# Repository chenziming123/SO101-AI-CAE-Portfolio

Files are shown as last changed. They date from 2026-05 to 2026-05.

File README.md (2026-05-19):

# SO-101 AI-Assisted CAD/CAE Robotic Arm Structure Project

> 基于开源 SO-101 follower arm 的 AI 辅助机械结构建模、参数化 CAD 迭代、URDF/PyBullet 回归验证和 CalculiX/Gmsh 有限元分析项目。

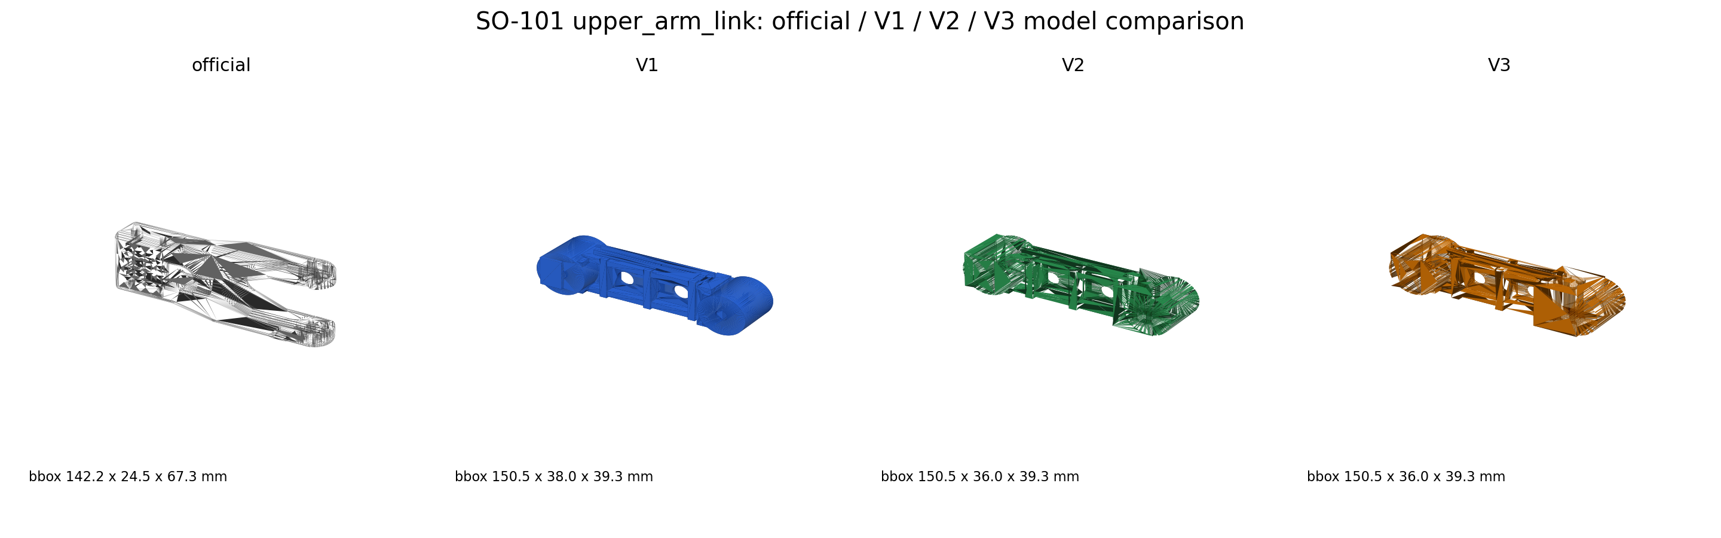
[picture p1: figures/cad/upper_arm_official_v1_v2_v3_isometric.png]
CAD iteration


## 项目定位

这个项目的目标不是只生成一个“看起来像机械臂”的模型，而是建立一条可以面向机械结构岗位展示的工程链：

1. 复现 SO-101 机械臂 baseline，并读取 CAD/STL/URDF 结构资源。
2. 对 official upper arm 做工作空间、静载力矩和结构瓶颈分析。
3. 使用 AI + CAD-as-code 思路生成 V1/V2/V3 参数化 upper arm。
4. 导出 STEP/STL，做孔位、沉孔、标准件装配和 URDF smoke test。
5. 使用 Gmsh / CalculiX / PyVista 对 official 与 V3 做同边界条件有限元对比。
6. 把模型、图片、数据、脚本和中文报告整理成可复核的作品集。

## 核心结果

| 版本 | 定位 | PLA 质量估算 | 体积变化 | 装配校核 | PyBullet smoke test |
|---|---|---:|---:|---|---|
| official | 开源 baseline | 145.49 g | 0.00% | 官方基准 | 通过 |
| V1 | 轻量化概念版 | 116.42 g | -19.98% | 关键接口不完整 | 通过 |
| V2 | 装配接口增强版 | 122.30 g | -15.94% | PASS | 通过 |
| V3 | 孔系余量修正版 | 126.35 g | -13.16% | PASS | 通过 |

full V3 clean FEA screening 结果：

| 版本 | 网格尺寸 | 节点数 | 四面体数 | 质量 | 最大位移 | 最大 von Mises | 屈服安全系数 |
|---|---:|---:|---:|---:|---:|---:|---:|
| official | 5.0 mm | 3750 | 12410 | 144.07 g | 0.024591 mm | 0.327 MPa | 153.11 |
| full V3 | 5.0 mm | 3255 | 11048 | 127.49 g | 0.071577 mm | 0.770 MPa | 64.96 |

结论：V3 相对 official 质量降低约 `11.51%`，但最大位移和应力上升，说明后续 V4 应优先加强中部梁、上下梁连接和肋板布局，而不是继续盲目减重。

## 仓库结构

```text
docs/      中文项目报告、流程说明、FEA 结论、工程说明
figures/   建模、仿真、FEA 和数据图
models/    V1/V2/V3 STEP/STL、装配检查模型、FEA clean STEP
data/      CSV/JSON 指标、孔位检查、力矩对比、FEA 结果
src/       CAD 生成、结构分析、URDF smoke test、FEA 脚本
tools/     项目辅助脚本
projects/  可独立查看的工程模块资料包
```

## 推荐阅读顺序

1. [`docs/01_project_overview_zh.md`](docs/01_project_overview_zh.md)
2. [`docs/02_cad_iteration_v1_v2_v3_zh.md`](docs/02_cad_iteration_v1_v2_v3_zh.md)
3. [`docs/03_fea_full_v3_clean_zh.md`](docs/03_fea_full_v3_clean_zh.md)
4. [`docs/04_text_to_cad_open_source_workflow_zh.md`](docs/04_text_to_cad_open_source_workflow_zh.md)
5. [`projects/text_to_cad_parametric_cad/README_zh.md`](projects/text_to_cad_parametric_cad/README_zh.md)
6. [`docs/08_text_to_cad_parametric_cad_workflow_zh.md`](docs/08_text_to_cad_parametric_cad_workflow_zh.md)
7. [`docs/05_project_explanation_zh.md`](docs/05_project_explanation_zh.md)

## 工程模块与证据目录

| 工程模块 | GitHub 对应内容 |
|---|---|
| Text-to-CAD机械结构参数化建模与工程校核流程 | [`projects/text_to_cad_parametric_cad/README_zh.md`](projects/text_to_cad_parametric_cad/README_zh.md)、[`docs/08_text_to_cad_parametric_cad_workflow_zh.md`](docs/08_text_to_cad_parametric_cad_workflow_zh.md) |
| SO-101机械臂结构仿真、装配验证与有限元分析 | [`docs/02_cad_iteration_v1_v2_v3_zh.md`](docs/02_cad_iteration_v1_v2_v3_zh.md)、[`docs/03_fea_full_v3_clean_zh.md`](docs/03_fea_full_v3_clean_zh.md)、`figures/fea/`、`data/fea/` |

## 关键图片

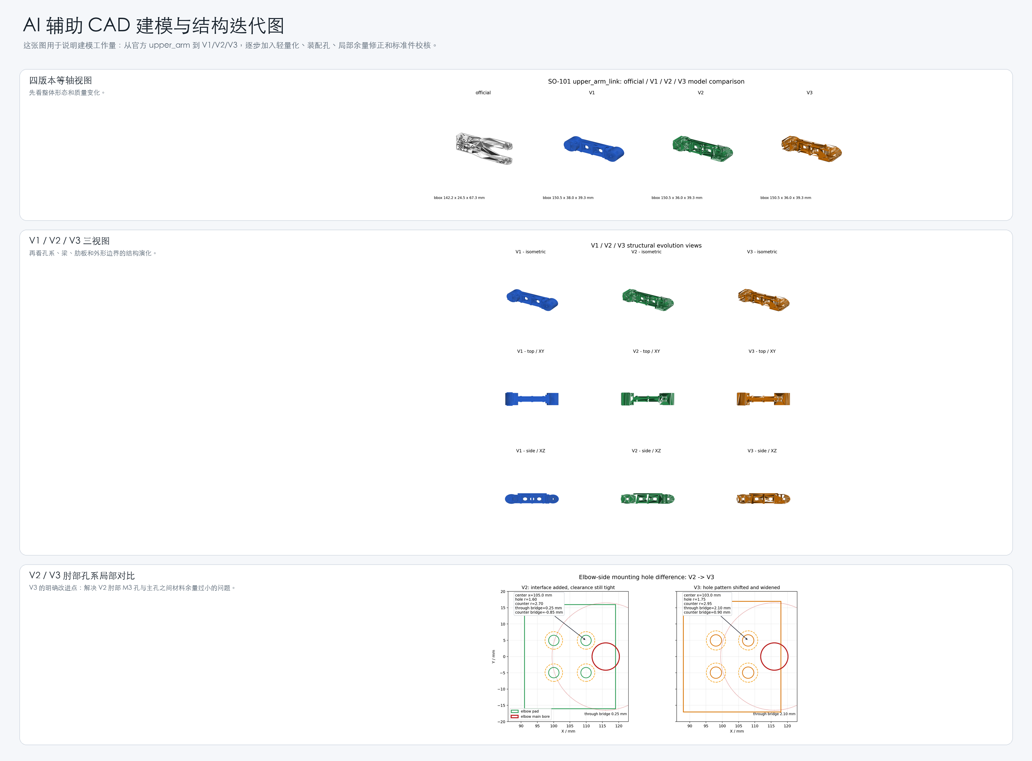
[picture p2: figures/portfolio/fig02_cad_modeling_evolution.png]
CAD evolution


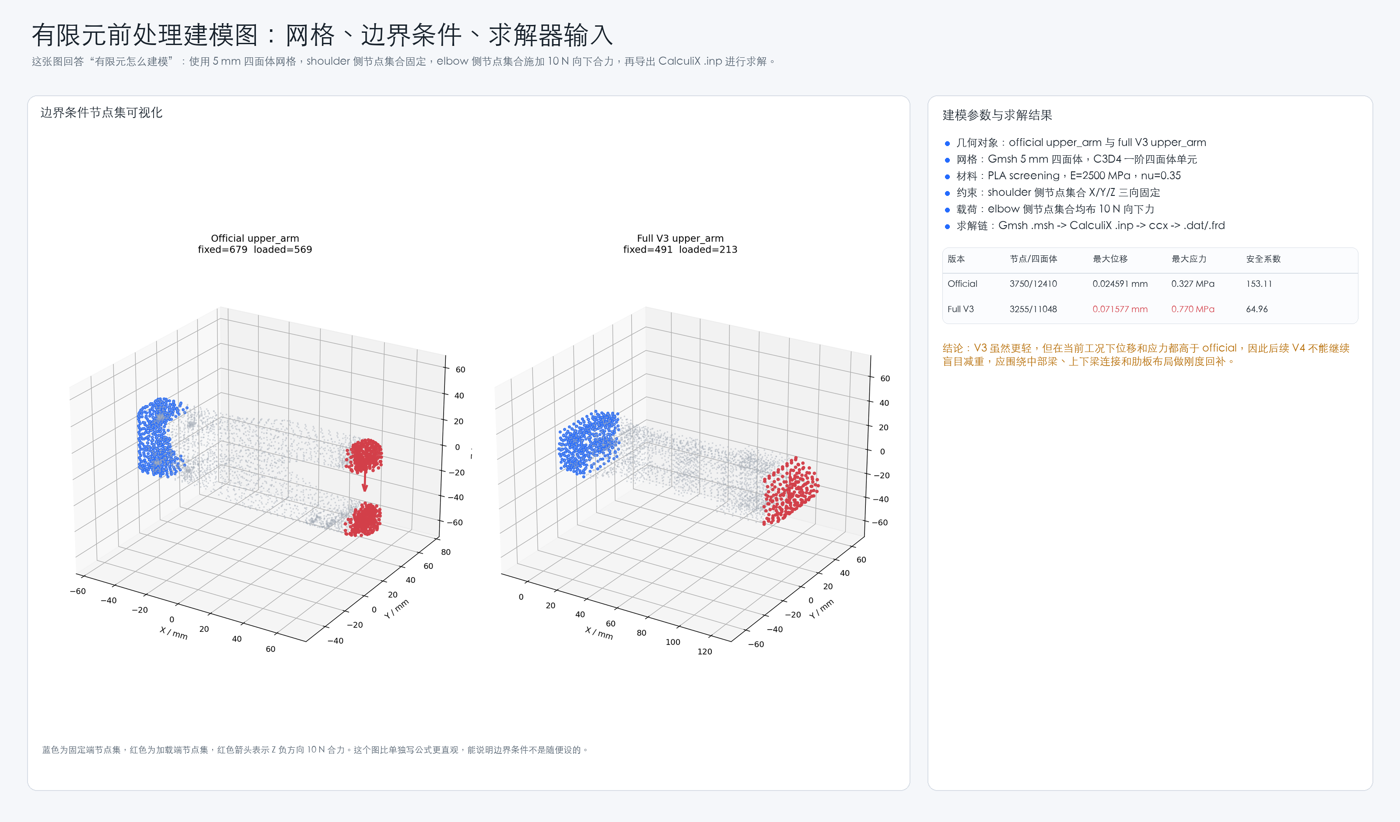
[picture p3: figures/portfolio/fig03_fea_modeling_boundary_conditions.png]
FEA boundary


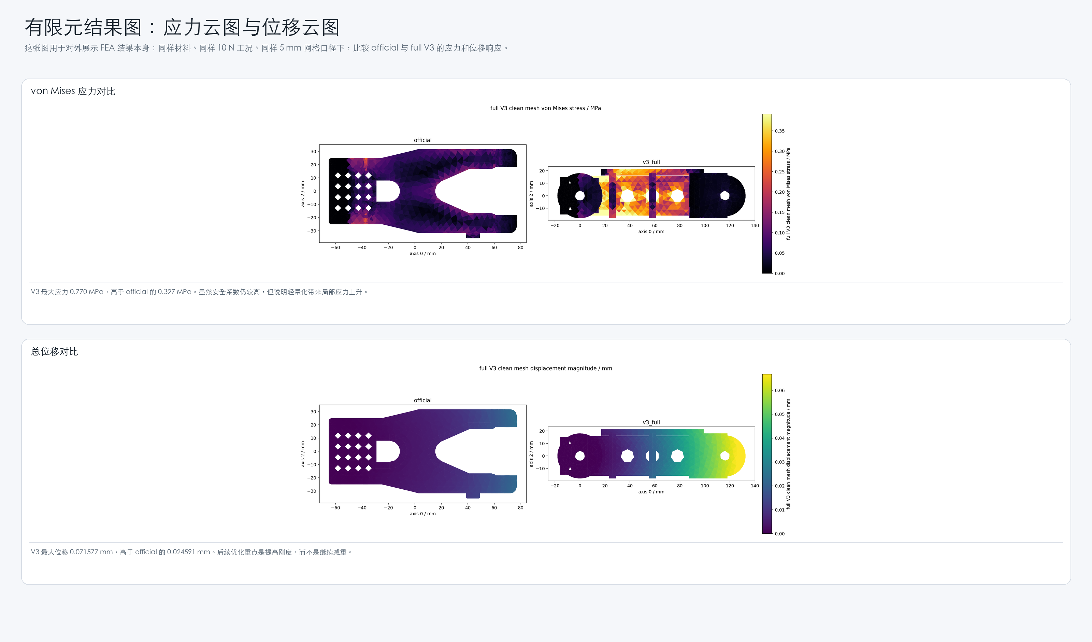
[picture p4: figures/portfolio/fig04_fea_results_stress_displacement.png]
FEA results


## 复现实验环境

主要 Python 依赖：

- CAD 建模：`build123d`, `OCP`, `trimesh`
- 仿真/数据：`numpy`, `scipy`, `matplotlib`, `pybullet`
- 网格与 FEA 后处理：`gmsh`, `meshio`, `pyvista`
- 求解器：`CalculiX ccx`

完整环境建议见 [`docs/06_toolchain_feasibility_zh.md`](docs/06_toolchain_feasibility_zh.md)。

## 说明

本仓库是作品集整理版，只包含公开展示所需的模型、图片、数据、报告和代码。个人资料、联系方式、服务器凭据、临时缓存和完整私有工作目录没有上传。

SO-101 baseline 资源来自开源项目，相关第三方资源权利归原项目所有；本仓库中的 AI 辅助 CAD/CAE 脚本、分析报告和整理图表用于学习与作品集展示。

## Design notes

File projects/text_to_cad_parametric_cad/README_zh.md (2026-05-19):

# Text-to-CAD 参数化机械结构建模与工程校核

本目录把 Text-to-CAD 相关的模型、图片、数据和代码集中在一起，便于独立查看这一模块的工程链路。

## 模块目标

将自然语言结构需求转化为可复现的参数化 CAD 脚本，并通过 STEP/STL 导出、B-Rep 特征校核、标准件装配检查、URDF 回归和 FEA 前处理验证模型可用性。

## 目录结构

```text
figures/      CAD 迭代图、三视图、孔系局部差异图
data/         体积/质量指标、孔位校核、装配检查 JSON/CSV
code/cad/     V1/V2/V3 CAD 生成、验证、孔位检查和 URDF smoke test 代码
models/       V1/V2/V3 STEP/STL 模型
assemblies/   V2/V3 简化标准件装配 STEP/STL
reports/      V1/V2/V3 设计报告和孔位校核报告
```

## 核心流程

```mermaid
flowchart LR
  A["结构需求"] --> B["参数拆解"]
  B --> C["build123d / OCP 建模脚本"]
  C --> D["STEP / STL 导出"]
  D --> E["B-Rep 圆柱特征识别"]
  E --> F["孔位 / 沉孔 / 装配余量检查"]
  F --> G["标准件简化装配"]
  G --> H["URDF / PyBullet 回归"]
  H --> I["FEA 前处理与下一版改进"]
```

## 模型迭代

| 版本 | 文件 | 设计目标 | 工程校核 |
|---|---|---|---|
| V1 | `models/upper_arm_v1_ai_rebuild.step` | 轻量化概念重建 | 可导出 STEP/STL，关键装配接口不足 |
| V2 | `models/upper_arm_v2_ai_rebuild.step` | 补齐 M3 孔、沉孔、肩部夹紧/定位孔 | 装配表达更完整，肘部孔系余量偏紧 |
| V3 | `models/upper_arm_v3_ai_rebuild.step` | 修正肘部孔位、孔径、沉孔和局部 pad | 孔位复核 PASS，标准件装配检查 PASS |

## 关键图

CAD evolution

Official V1 V2 V3

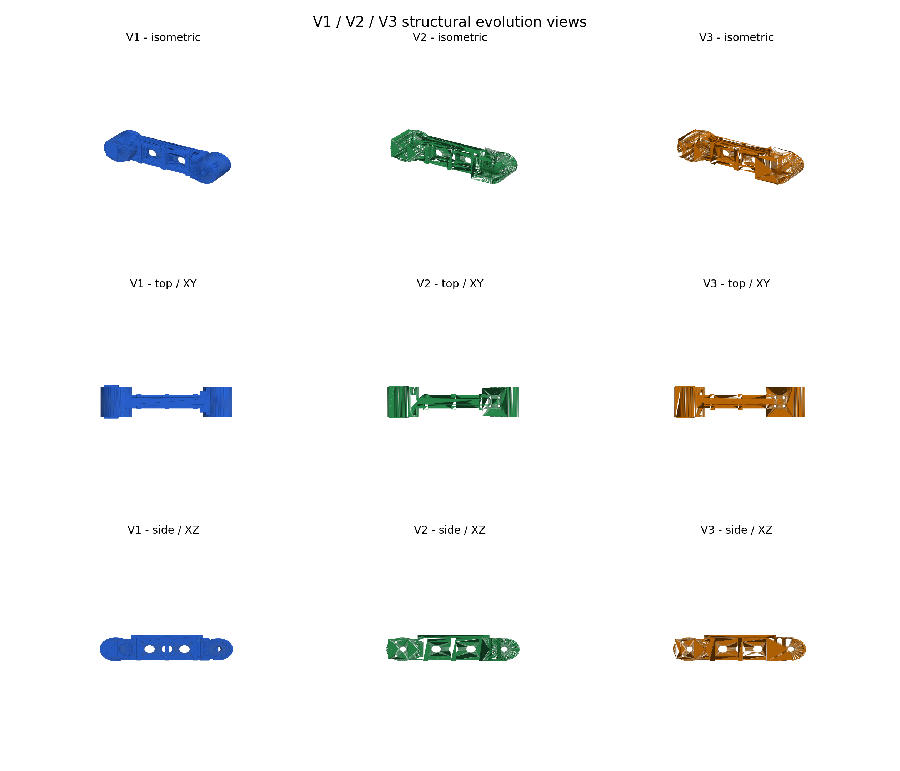
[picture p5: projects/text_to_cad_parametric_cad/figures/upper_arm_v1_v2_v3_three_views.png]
Three views


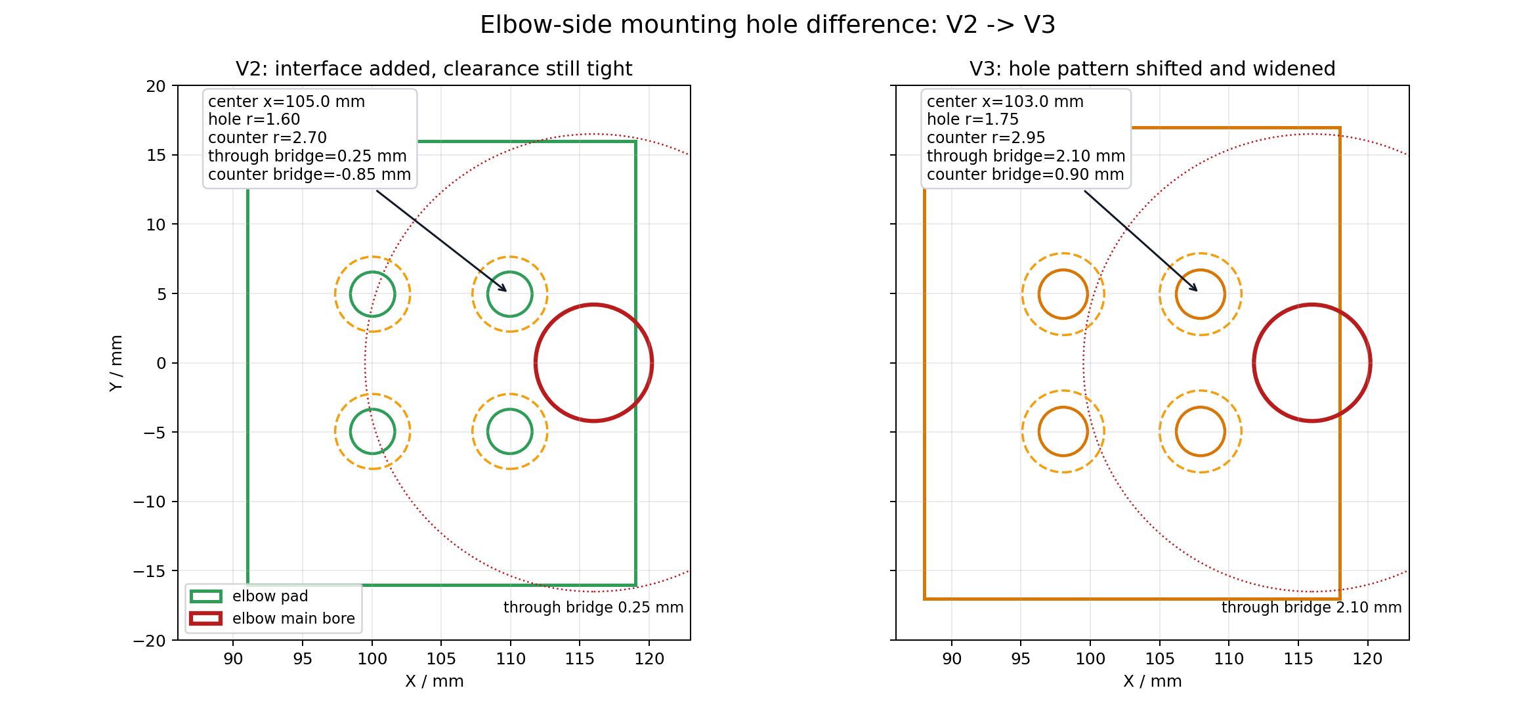
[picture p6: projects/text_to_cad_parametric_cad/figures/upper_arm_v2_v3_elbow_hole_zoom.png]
Elbow hole zoom


## 数据文件

关键汇总：

- `data/upper_arm_v1_v2_v3_key_metrics.csv`

V1/V2/V3 CAD 验证：

- `data/upper_arm_v1_validation.json`
- `data/upper_arm_v2_validation.json`
- `data/upper_arm_v3_validation.json`

孔位与圆柱特征校核：

- `data/upper_arm_v1_mounting_check.json`
- `data/upper_arm_v2_mounting_check.json`
- `data/upper_arm_v3_mounting_check.json`
- `data/upper_arm_v1_mounting_cylinders.csv`
- `data/upper_arm_v2_mounting_cylinders.csv`
- `data/upper_arm_v3_mounting_cylinders.csv`

标准件装配检查：

- `data/upper_arm_v2_standard_part_check.json`
- `data/upper_arm_v2_standard_part_checks.csv`
- `data/upper_arm_v3_standard_part_check.json`
- `data/upper_arm_v3_standard_part_checks.csv`

## 代码入口

CAD 生成：

```bash
python code/cad/upper_arm_v1/upper_arm_v1_cad.py
python code/cad/upper_arm_v2/upper_arm_v2_cad.py
python code/cad/upper_arm_v3/upper_arm_v3_cad.py
```

几何与孔位校核：

```bash
python code/cad/upper_arm_v1/validate_upper_arm_v1.py
python code/cad/upper_arm_v2/validate_upper_arm_v2.py
python code/cad/upper_arm_v3/validate_upper_arm_v3.py

python code/cad/upper_arm_v1/upper_arm_v1_mounting_check.py
python code/cad/upper_arm_v2/upper_arm_v2_mounting_check.py
python code/cad/upper_arm_v3/upper_arm_v3_mounting_check.py
```

标准件装配检查：

```bash
python code/cad/upper_arm_v2/upper_arm_v2_standard_part_assembly_check.py
python code/cad/upper_arm_v3/upper_arm_v3_standard_part_assembly_check.py
```

URDF / PyBullet 回归：

```bash
python code/cad/upper_arm_v1/upper_arm_v1_urdf_smoke.py
python code/cad/upper_arm_v2/upper_arm_v2_urdf_smoke.py
python code/cad/upper_arm_v3/upper_arm_v3_urdf_smoke.py
```

## 工程结论

Text-to-CAD 在本项目中的作用不是替代工程验证，而是提高结构方案生成和参数化建模效率。最终模型必须经过 STEP 特征级孔位校核、标准件装配检查、URDF/PyBullet 回归和 FEA 结果约束，才能进入下一轮结构设计。

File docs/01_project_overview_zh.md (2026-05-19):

# 项目总览：SO-101 AI 辅助机械臂结构建模与 CAE 验证

## 项目目标

围绕开源 SO-101 follower arm，构建一个面向机械结构/CAE 岗位的作品集项目。项目强调“AI 参与工程流程”，但不把 AI 输出当作最终答案，而是用 CAD 特征校核、URDF 运动学回归、静载力矩分析和有限元结果反向约束设计。

## 技术路线

```mermaid
flowchart LR
  A["开源 SO-101 baseline"] --> B["CAD/STL/URDF 资产盘点"]
  B --> C["PyBullet baseline 运动验证"]
  C --> D["工作空间和静载力矩分析"]
  D --> E["锁定 upper_arm_link 优化对象"]
  E --> F["AI + 参数化 CAD 生成 V1/V2/V3"]
  F --> G["STEP/STL 导出与孔位校核"]
  G --> H["URDF smoke test 与力矩回归"]
  H --> I["Gmsh/CalculiX 静力有限元"]
  I --> J["V4 结构加强方向"]
```

## 作品集中能体现的能力

- 机械结构拆解：从整机中定位 upper arm 的结构和受力角色。
- CAD 建模：用参数化脚本生成可导出的 STEP/STL，而不是只做图片。
- 装配意识：检查孔位、沉孔、标准件和接口余量。
- 仿真闭环：把 CAD 改动接回 URDF/PyBullet 验证运动链。
- CAE 能力：搭建 Gmsh/CalculiX 有限元流程，输出应力/位移/安全系数。
- AI 辅助工程：用 AI 提高建模、脚本、报告和设计迭代效率，同时用工程校核约束 AI 结果。

## 当前阶段结论

V3 已经实现了从 CAD 到 URDF 到 FEA 的完整闭环。它相对 official 更轻，但 full V3 FEA 结果显示刚度下降明显，下一阶段应基于 FEA 结果设计 V4，加强中部梁、上下梁连接和肋板布局。

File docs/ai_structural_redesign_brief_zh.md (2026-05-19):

# SO-101 Follower AI 结构重建设计 Brief

## 目标

使用 AI 辅助 CAD 生成方法，对 SO-101 的选定结构件进行参数化重建和局部改进，同时保留官方机械臂的运动学结构。

## 必须保留的内容

- 保留官方 joint 名称、joint axis 和运动链。
- 第一轮重建设计中保留 `shoulder_lift`、`elbow_flex`、`wrist_flex`、`wrist_roll` 和 gripper frame 的位置。
- 保留舵机安装接口、舵盘间隙、螺丝孔位和 URDF link 归属关系。
- 不修改 `00_source_snapshot/`；所有改进版 CAD 放在 `05_improved_design/`。

## 来自 URDF 的关键 Baseline 尺寸

- shoulder_lift 到 elbow_flex 近似跨度：116.0 mm
- elbow_flex 到 wrist_flex 近似跨度：135.0 mm
- wrist_flex 到 wrist_roll 近似跨度：63.7 mm
- wrist/gripper frame offset 贡献：98.4 mm

## 重建设计目标

### 目标 1：upper_arm_link

- 控制关节：`shoulder_lift`
- 风险分数：100.0 / 100
- baseline p95 弯矩：1.1496 Nm
- 简化 p95 转角估计：2.660 deg
- 改进方向：通过加强筋、盒式截面和线槽提高弱轴刚度，同时不移动肩部和肘部关节 frame。
- 必须保留的接口：保留 `shoulder_lift` 和 `elbow_flex` 的 joint origin、axis、舵盘间隙和螺丝安装接口。

### 目标 2：lower_arm_link

- 控制关节：`elbow_flex`
- 风险分数：73.4 / 100
- baseline p95 弯矩：0.7142 Nm
- 简化 p95 转角估计：2.158 deg
- 改进方向：降低远端质量，并在腕部电机座和线束应力释放区域增加局部加强。
- 必须保留的接口：保留 `elbow_flex` 和 `wrist_flex` 的 joint origin、腕部电机座对齐关系和腕部安装孔位。

### 目标 3：wrist_gripper_module

- 控制关节：`wrist_flex`
- 风险分数：53.2 / 100
- baseline p95 弯矩：0.2725 Nm
- 简化 p95 转角估计：2.194 deg
- 改进方向：降低远端质量，增加紧凑局部加强筋，并加入可换指尖或小型工具法兰。
- 必须保留的接口：保留 `wrist_flex`、`wrist_roll`、`gripper` joint frame、tool frame 和夹爪开合几何兼容性。

## 第一版改进 CAD 的成功标准

- 输出可编辑的 build123d/Python CAD 源文件，并导出 STEP/STL。
- 工作空间可达性接近官方 baseline。
- 在不改变运动学 frame 的前提下，降低远端质量或提高弱轴有效刚度。
- mesh 替换后通过 PyBullet URDF 加载和随机运动 smoke test。
- 如果质量、刚度或工作空间出现取舍，必须在报告中明确说明。

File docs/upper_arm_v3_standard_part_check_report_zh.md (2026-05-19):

# upper_arm_v3 标准件装配与简化干涉检查报告

## 这一步在做什么

Step 15 针对 Step 14 在 V2 中发现的肘部孔系余量问题，生成 V3 的简化标准件装配检查。

本步骤用简化 D8 主轴、M3 螺钉、M3 螺钉头和简化舵机连接板，检查 V3 的孔径、沉孔、孔间材料和 pad 边缘材料是否可接受。

## V3 相比 V2 的修改

- 肘部 2x2 安装孔中心从 x=105.0 mm 移到 x=103.0 mm，让孔系远离 elbow 主孔。
- 肘部 M3 通孔半径从 1.60 mm 放宽到 1.75 mm，提高打印后螺钉装入成功率。
- 肘部 M3 沉孔半径从 2.70 mm 放宽到 2.95 mm，提高螺钉头装配余量。
- 肘部 pad 从 28 x 32 x 35 mm 增加到 30 x 34 x 36 mm，用局部加厚抵消放宽孔径带来的材料削弱。

## 标准件简化假设

- 主关节轴/轴套：半径 4.00 mm，对应约 D8 标准件包络。
- 肘部安装螺钉：M3 简化螺钉，杆部半径 1.50 mm，头部半径 2.60 mm，高度 2.00 mm。
- 肩部夹紧/定位螺钉：M3 简化螺钉，杆部半径 1.50 mm，外侧头部半径 3.00 mm。
- 肘部简化舵机/连接板 footprint：22.0 x 22.0 mm。

## 总体结论

- 装配检查总体状态：`PASS`。
- FAIL 项数量：0。
- WARN 项数量：0。
- Step 14 中 V2 的 3 个装配余量 WARN 项在 V3 中已消除。

## 检查明细

| 检查项 | 要求 | 实测/计算 | 状态 | 说明 |
|---|---|---|---|---|
| 主关节 D8 轴/轴套径向余量 | 孔半径 4.20 mm，应大于标准件半径 4.00 mm | 0.200 mm | PASS | 用于判断 shoulder/elbow 主轴或轴套是否能装入。 |
| 肘部 M3 螺钉通孔径向余量 | 孔半径 1.75 mm，应大于 M3 螺钉半径 1.50 mm | 0.250 mm | PASS | V3 已将 V2 的偏紧通孔放宽，给 3D 打印误差留出更稳定余量。 |
| 肘部 M3 螺钉头沉孔径向余量 | 沉孔半径 2.95 mm，应大于头部半径 2.60 mm | 0.350 mm | PASS | V3 已放宽沉孔半径，降低实际螺钉头装不进去的风险。 |
| 肘部 M3 螺钉头沉孔深度余量 | 沉孔深度 2.40 mm，应大于头部高度 2.00 mm | 0.400 mm | PASS | 沉孔深度可容纳简化螺钉头。 |
| 肘部安装孔到 pad 边缘最小材料 | 建议 >= 2.0 mm | 通孔边缘 8.300 mm，沉孔边缘 7.100 mm | PASS | V3 同时加大 elbow pad，使放宽孔径后仍保留边缘材料。 |
| 肘部 2x2 孔间最小材料 | 建议通孔/沉孔之间保留 >= 2.0 mm | 通孔间 6.400 mm，沉孔间 4.000 mm | PASS | 孔系自身材料余量仍可接受。 |
| 肘部安装孔与 elbow 主孔最小孔间材料 | 保守按沉孔外缘建议 >= 0.8 mm | 通孔外缘 2.100 mm，沉孔外缘 0.900 mm | PASS | 这是 Step 14 的主要风险项。V3 将孔系向近端移动后，最近 M3 孔与 elbow 主孔之间的材料桥明显增加。 |
| 肩部 M3 夹紧/定位孔径向余量 | 孔半径 2.00 mm，应大于 M3 螺钉半径 1.50 mm | 0.500 mm | PASS | 肩部侧向孔给 M3 螺钉留有较宽松余量。 |
| 肩部夹紧孔到 pad 边缘最小材料 | 建议 >= 2.0 mm | 2.500 mm | PASS | V3 没有改肩部接口，该项继承 V2 的可接受结果。 |
| 肩部夹紧孔与 shoulder 主孔最小孔间材料 | 建议 >= 2.0 mm | 7.000 mm | PASS | 肩部夹紧孔与主孔之间有较充足材料。 |
| 简化舵机/连接板 footprint 是否落在 elbow pad 内 | 参考板投影应在 pad 内 | 最小边缘余量 4.000 mm | PASS | 用于检查简化 mating plate 不会明显悬空。 |

## 工程解释

- V3 的主关节孔、肩部夹紧孔和肘部 M3 孔在简化标准件尺寸下都能装入。
- V3 用少量局部材料换取更好的装配余量，这比继续追求极限轻量化更适合作品集阶段的工程表达。
- 本检查仍然是设计阶段筛查，不等同于真实打印、螺钉锁紧、疲劳和冲击载荷验证。

## 下一步

Step 16 应将 V3 接回 URDF/PyBullet，复查关节链、末端运动学和惯量更新后的静载力矩，确认 V3 的局部加厚没有明显破坏前面建立的仿真 baseline。

## 输出文件

- 简化标准件装配 STEP：`<repo>/05_improved_design/upper_arm_v3/assembly_check/upper_arm_v3_simplified_standard_parts_assembly.step`
- 简化标准件装配 STL：`<repo>/05_improved_design/upper_arm_v3/assembly_check/upper_arm_v3_simplified_standard_parts_assembly.stl`
- 结构化结果 JSON：`<repo>/05_improved_design/upper_arm_v3/assembly_check/upper_arm_v3_standard_part_check.json`
- 检查明细 CSV：`<repo>/05_improved_design/upper_arm_v3/assembly_check/upper_arm_v3_standard_part_checks.csv`

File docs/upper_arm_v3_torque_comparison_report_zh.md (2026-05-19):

# upper_arm_v3 惯量更新与静载力矩对比报告

## 这一步在做什么

将 `upper_arm_v3` 的体积变化转化为 URDF inertial screening 参数，并与官方 SO-101 baseline 做静载关节力矩对比。

## 方法

- 保留官方 URDF 作为 baseline，不覆盖 `00_source_snapshot/`。
- 使用 V3 STL 与官方 upper arm STL 的体积比例，按比例缩放官方 `upper_arm_link` 的质量和惯量张量。
- 生成 `so101_upper_arm_v3_inertial_scaled.urdf`。
- 使用同一批随机关节姿态，对官方版和 V3 inertial 版计算静载关节力矩。
- 该方法是工程筛查，不是最终真实惯量标定。

## 质量与惯量更新

- 官方 upper arm STL 体积：117328.19 mm^3
- V1 upper arm STL 体积：93885.71 mm^3
- V2 upper arm STL 体积：98626.10 mm^3
- V3 upper arm STL 体积：101891.50 mm^3
- V1 / 官方体积比例：0.8002
- V2 / 官方体积比例：0.8406
- V3 / 官方体积比例：0.8684
- V2 / V1 体积比例：1.0505
- V3 / V2 体积比例：1.0331
- 官方 URDF `upper_arm_link` 质量：0.103000 kg
- V3 screening 质量：0.089448 kg
- V3 相对官方质量变化：-0.013552 kg (-13.16%)

说明：官方 URDF link 质量和 STL 体积估算质量并不完全一致。因此本步骤采用“URDF 质量按 STL 体积比例缩放”的筛查方式，目的是观察趋势，不作为最终物理参数。

## 0.10 kg Payload 下的 p95 静载力矩对比

| 关节 | 官方 p95 Nm | V3 p95 Nm | 变化 Nm | 变化比例 |
|---|---:|---:|---:|---:|
| shoulder_pan | 0.0000 | 0.0000 | -0.0000 | -0.98% |
| shoulder_lift | 1.1422 | 1.1313 | -0.0109 | -0.95% |
| elbow_flex | 0.7130 | 0.7130 | 0.0000 | 0.00% |
| wrist_flex | 0.2724 | 0.2724 | 0.0000 | 0.00% |
| wrist_roll | 0.0050 | 0.0050 | 0.0000 | 0.00% |

## Official / V1 / V2 / V3 四版本对比

| 关节 | 官方 p95 Nm | V1 p95 Nm | V2 p95 Nm | V3 p95 Nm | V3 相对 V2 变化 Nm |
|---|---:|---:|---:|---:|---:|
| shoulder_pan | 0.0000 | 0.0000 | 0.0000 | 0.0000 | 0.0000 |
| shoulder_lift | 1.1422 | 1.1254 | 1.1288 | 1.1313 | 0.0025 |
| elbow_flex | 0.7130 | 0.7130 | 0.7130 | 0.7130 | 0.0000 |
| wrist_flex | 0.2724 | 0.2724 | 0.2724 | 0.2724 | -0.0000 |
| wrist_roll | 0.0050 | 0.0050 | 0.0050 | 0.0050 | -0.0000 |

## 主要结论

- `shoulder_lift` p95 力矩：1.1422 -> 1.1313 Nm，变化 -0.0109 Nm (-0.95%)。
- `elbow_flex` p95 力矩：0.7130 -> 0.7130 Nm，变化 0.0000 Nm (0.00%)。
- V3 比 V2 略重，因为它继续保留并加厚了肘部孔系周边材料；这一点与 Step 15 的装配余量修复目标一致。
- 结果仍符合机械直觉：upper arm 的质量变化主要影响 `shoulder_lift`，对下游 `elbow_flex` 和 `wrist_flex` 影响很小。

## 当前限制

- 当前 inertia 是按体积比例缩放的筛查值，不是从 CAD 质量属性直接导出的最终惯量。
- Official / V1 / V2 / V3 四版本对比使用同一批随机关节姿态重新计算，避免不同随机采样导致的 p95 细微偏差。
- 尚未替换 collision mesh，也尚未引入舵机、轴承、螺丝等标准件做完整装配干涉检查。
- 下一步建议整理 official/V1/V2/V3 总对比报告，或者继续向 lower arm / wrist 结构推进。

## 生成文件

- `05_improved_design/upper_arm_v3/inertial_compare/so101_upper_arm_v3_inertial_scaled.urdf`
- `05_improved_design/upper_arm_v3/inertial_compare/upper_arm_v3_torque_comparison.csv`
- `05_improved_design/upper_arm_v3/inertial_compare/upper_arm_v3_torque_comparison_plot.png`
- `05_improved_design/upper_arm_v3/inertial_compare/upper_arm_v3_torque_comparison_report_zh.md`
- 静态姿态数量（含 zero pose）：10001

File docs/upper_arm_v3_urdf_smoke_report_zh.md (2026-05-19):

# upper_arm_v3 接回 URDF/PyBullet Smoke Test 报告

## 这一步在做什么

验证 `upper_arm_v3` 的 STL 是否可以接回 SO-101 的 URDF/PyBullet 仿真链路，并确认 V3 的结构修改没有破坏原机器人的关节链和末端运动学。

## 做法

- 复制官方 `Simulation_SO101/assets` 到 V3 的 `urdf_smoke/assets`。
- 将 `upper_arm_v3_ai_rebuild.stl` 从毫米单位缩放为米单位，生成 `upper_arm_v3_ai_rebuild_m.stl`。
- 复制官方 URDF，生成 `so101_upper_arm_v3_visual_smoke.urdf`。
- 只替换 `upper_arm_link` 的 visual mesh，不修改 collision、joint 和 inertial。
- 使用同一批随机关节角度比较官方 URDF 和 V3 visual URDF 的末端位置。

## 输入文件

- 官方 URDF：`<repo>/00_source_snapshot/Simulation_SO101/so101_new_calib.urdf`
- V3 visual smoke URDF：`<repo>/05_improved_design/upper_arm_v3/urdf_smoke/so101_upper_arm_v3_visual_smoke.urdf`

## Mesh 缩放检查

- V3 原始 STL 包围盒：[150.5, 36.0, 39.299999]
- 缩放后仿真 mesh 包围盒：[0.1505, 0.036, 0.0393] m
- 缩放后 mesh watertight：True

## PyBullet Smoke Test 结果

- 关节名称是否一致：True
- 官方关节数：7
- V3 关节数：7
- 随机姿态数量（含 zero pose）：2001
- zero pose 末端位置差：0.000000e+00 m
- 最大末端位置差：0.000000e+00 m
- 平均末端位置差：0.000000e+00 m

## 结论

- V3 visual URDF 可以被 PyBullet 加载。
- 关节数量和关节名称保持不变。
- 由于本步骤只替换 visual mesh，不修改 joint、collision、inertial，末端运动学与官方 baseline 保持一致。
- 这说明 V3 不只是 CAD 层面的修正件，已经重新进入 SO-101 的仿真链路。

## 当前限制

- 本 smoke test 只替换 visual mesh，尚未替换 collision mesh。
- 本步骤尚未把 V3 的质量和惯量写入 URDF。
- 下一步需要基于 V3 体积比例更新 inertial，并重新做静载力矩对比。

## 生成文件

- `05_improved_design/upper_arm_v3/urdf_smoke/so101_upper_arm_v3_visual_smoke.urdf`
- `05_improved_design/upper_arm_v3/urdf_smoke/assets/upper_arm_v3_ai_rebuild_m.stl`
- `05_improved_design/upper_arm_v3/urdf_smoke/upper_arm_v3_urdf_smoke_motion.csv`
- `05_improved_design/upper_arm_v3/urdf_smoke/upper_arm_v3_urdf_smoke_plot.png`
- `05_improved_design/upper_arm_v3/urdf_smoke/upper_arm_v3_urdf_smoke_report_zh.md`

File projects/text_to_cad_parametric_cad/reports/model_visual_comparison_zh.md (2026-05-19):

# upper_arm_link 模型图对比说明

## 目的

把 official、V1、V2、V3 的模型差异可视化，方便直接查看结构变化，而不是只看体积和力矩数字。

## 图片文件

- 四版本整体等轴视图：`upper_arm_official_v1_v2_v3_isometric.png`
- V1/V2/V3 三视图演化：`upper_arm_v1_v2_v3_three_views.png`
- V2/V3 肘部孔系局部对比：`upper_arm_v2_v3_elbow_hole_zoom.png`

## 主要观察点

- V1：主要体现轻量化骨架，主关节中心距和主孔轴线保留，但装配孔系不足。
- V2：增加肘部 2x2 安装孔、沉孔和肩部夹紧/定位孔，装配表达更完整。
- V3：在 V2 基础上移动并放宽肘部孔系，局部 pad 加厚，用少量质量换取标准件装配余量。
- official：作为开源 baseline，不要求和 AI 重建件外形完全一致，主要用于对比体积、质量和接口约束。

## 当前限制

- 这些图是 STL/参数的可视化渲染，不是生产图纸。
- official STL 与 V1/V2/V3 的本地坐标系不完全一致，因此 official 主要作为外观和体积参照，不建议直接和 V1/V2/V3 叠加判断孔位。

四版本整体等轴视图

V1/V2/V3 三视图演化

V2/V3 肘部孔系局部对比

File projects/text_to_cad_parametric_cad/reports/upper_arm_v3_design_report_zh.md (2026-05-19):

# upper_arm_link V3 AI 辅助结构迭代设计报告

## 这一步在做什么

Step 15 在 V2 标准件装配检查的基础上，针对肘部孔系余量不足的问题生成 `upper_arm_v3`。

V3 不是推翻 V2，而是做一次明确的局部工程修正：保持 shoulder/elbow 主关节轴线、116.000 mm 中心距和整体运动链不变，只优化肘部 2x2 安装孔、沉孔和局部 pad。

## 为什么要做 V3

Step 14 中 V2 的总体状态是 `PASS_WITH_WARNINGS`，没有 FAIL，但有 3 个关键 WARN：

- 肘部 M3 通孔径向余量只有 0.100 mm，真实打印后偏紧。
- 肘部 M3 螺钉头沉孔径向余量只有 0.100 mm，螺钉头适配风险偏高。
- 最近的肘部 M3 孔与 elbow 主孔之间材料余量约 0.250 mm，局部材料桥偏薄。

这些问题说明 V2 已经能表达装配孔位，但还不适合作为更可信的可打印结构版本。V3 的目标就是把这些警告转化为设计修改和再次验证。

## V3 设计修改

| 项目 | V2 | V3 | 作用 |
|---|---:|---:|---|
| 肘部 2x2 孔系中心 x | 105.0 mm | 103.0 mm | 让最近的 M3 孔远离 elbow 主孔 |
| 肘部 M3 通孔半径 | 1.60 mm | 1.75 mm | 增大 M3 螺钉装配余量 |
| 肘部 M3 沉孔半径 | 2.70 mm | 2.95 mm | 增大螺钉头装配余量 |
| 肘部 M3 沉孔深度 | 2.20 mm | 2.40 mm | 增大螺钉头高度余量 |
| 肘部 pad 尺寸 | 28 x 32 x 35 mm | 30 x 34 x 36 mm | 用局部加厚抵消孔径放大带来的材料削弱 |

## 生成文件

- 参数化 CAD 源码：`05_improved_design/upper_arm_v3/upper_arm_v3_cad.py`
- V3 STEP：`05_improved_design/upper_arm_v3/upper_arm_v3_ai_rebuild.step`
- V3 STL：`05_improved_design/upper_arm_v3/upper_arm_v3_ai_rebuild.stl`
- 参数 JSON：`05_improved_design/upper_arm_v3/upper_arm_v3_parameters.json`
- 几何验证报告：`05_improved_design/upper_arm_v3/upper_arm_v3_validation_zh.md`
- CAD 孔位复核报告：`05_improved_design/upper_arm_v3/mounting_check/upper_arm_v3_mounting_check_report_zh.md`
- 标准件装配检查报告：`05_improved_design/upper_arm_v3/assembly_check/upper_arm_v3_standard_part_check_report_zh.md`
- 简化标准件装配 STEP：`05_improved_design/upper_arm_v3/assembly_check/upper_arm_v3_simplified_standard_parts_assembly.step`
- 简化标准件装配 STL：`05_improved_design/upper_arm_v3/assembly_check/upper_arm_v3_simplified_standard_parts_assembly.stl`

## 几何与质量对比

| 模型 | STL 体积 | PLA 粗估质量 | watertight | 说明 |
|---|---:|---:|---|---|
| official upper arm | 117328.19 mm^3 | 145.49 g | true | 官方结构 |
| upper_arm_v1 | 93885.71 mm^3 | 116.42 g | true | 轻量化概念版 |
| upper_arm_v2 | 98626.10 mm^3 | 122.30 g | true | 增加装配孔位版 |
| upper_arm_v3 | 101891.50 mm^3 | 126.35 g | true | 修正肘部孔系余量版 |

关键解释：

- V3 相对官方 upper arm 体积仍减少约 13.15%，PLA 粗估质量少约 19.14 g。
- V3 相对 V2 体积增加约 3.31%，PLA 粗估质量增加约 4.05 g。
- 这部分增加的质量来自肘部 pad 局部加厚和孔系余量修正，属于用小幅质量代价换取装配可靠性。

## CAD 孔位复核结果

V3 的 CAD 圆柱特征复核总体为 `PASS`。

关键通过项：

- 肩部主孔半径：4.200 mm，PASS。
- 肘部主孔半径：4.200 mm，PASS。
- 肩部到肘部主孔中心距：116.000 mm，PASS。
- 主孔轴线方向：Y 轴，误差 0.000 deg，PASS。
- 肘部 2x2 安装孔：4 个 Z 轴通孔全部检测到，孔半径 1.750 mm，PASS。
- 肩部侧向夹紧/定位孔：2 个 Y 轴通孔全部检测到，孔半径 2.000 mm，PASS。

这说明 V3 没有破坏 V2 已建立的主关节接口和二级装配孔系。

## 标准件装配检查结果

V3 的简化标准件装配检查总体为 `PASS`，FAIL 数量 0，WARN 数量 0。

| 检查项 | 结果 |
|---|---|
| 主关节 D8 轴/轴套径向余量 | 0.200 mm，PASS |
| 肘部 M3 通孔径向余量 | 0.250 mm，PASS |
| 肘部 M3 螺钉头沉孔径向余量 | 0.350 mm，PASS |
| 肘部 M3 螺钉头沉孔深度余量 | 0.400 mm，PASS |
| 肘部安装孔到 pad 边缘最小材料 | 通孔 8.300 mm，沉孔 7.100 mm，PASS |
| 肘部 2x2 孔间最小材料 | 通孔 6.400 mm，沉孔 4.000 mm，PASS |
| 肘部安装孔与 elbow 主孔最小孔间材料 | 通孔外缘 2.100 mm，沉孔外缘 0.900 mm，PASS |
| 肩部 M3 夹紧/定位孔径向余量 | 0.500 mm，PASS |
| 肩部夹紧孔到 pad 边缘最小材料 | 2.500 mm，PASS |
| 肩部夹紧孔与 shoulder 主孔最小孔间材料 | 7.000 mm，PASS |
| 简化舵机/连接板 footprint | 最小边缘余量 4.000 mm，PASS |

## 工程意义

V3 的价值不在于“又生成了一个模型”，而在于形成了一个完整的工程迭代闭环：

1. V2 做出装配孔位。
2. Step 14 用标准件装配检查发现具体风险。
3. V3 针对风险修改参数。
4. 再用 CAD 孔位复核和标准件装配检查证明问题被修复。

这比单纯展示一个 AI 生成模型更有说服力，因为它体现了机械结构设计中“发现问题、定位原因、修改结构、重新验证”的过程。

## 当前边界

- V3 仍然是基于简化标准件的设计阶段检查，不等于真实生产装配认证。
- 尚未做真实 FEA、打印方向、层间强度、螺钉预紧力和疲劳验证。
- 尚未将 V3 接回 URDF/PyBullet 做惯量更新和静载力矩回归。

## 下一步

Step 17 可以继续做两件事之一：

- 整理 upper arm 这一条线的作品集总稿，把 baseline、V1、V2、V3、CAD、装配检查、URDF smoke 和惯量回归串成一页能讲清的流程。
- 继续推进下一个结构件，优先选择 lower arm，用同样方法复用 baseline -> CAD -> URDF -> 力矩的闭环。

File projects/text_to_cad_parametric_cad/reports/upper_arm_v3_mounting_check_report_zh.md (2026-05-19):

# upper_arm_v3 CAD 孔位复核报告

## 这一步在做什么

检查 V3 在修复肘部孔系余量后，主关节接口和新增装配孔系是否仍然能从 STEP 圆柱特征中被检测到。

## 圆柱特征统计

| 模型 | 去重后圆柱特征数 | X 轴 | Y 轴 | Z 轴 | 斜轴 |
|---|---:|---:|---:|---:|---:|
| official_upper_arm_step | 83 | 26 | 8 | 35 | 14 |
| upper_arm_v2_step | 21 | 0 | 9 | 12 | 0 |
| upper_arm_v3_step | 21 | 0 | 9 | 12 | 0 |

## 主关节接口复核

| 检查项 | 设计要求 | 实测/检测结果 | 结论 | 作用 |
|---|---|---|---|---|
| 肩部主孔半径 | 4.200 mm | r=4.200, loc=(0.000, 22.000, -0.000), axis=(-0.000, 1.000, -0.000) | 通过 | 保持 shoulder_lift 轴线接口。 |
| 肘部主孔半径 | 4.200 mm | r=4.200, loc=(116.000, 22.000, -0.000), axis=(-0.000, 1.000, -0.000) | 通过 | 保持 elbow_flex 轴线接口。 |
| 肩部到肘部主孔中心距 | 116.000 mm | 116.000 | 通过 | 保证 V3 不破坏原运动链长度。 |
| 主孔轴线方向 | 沿 Y 轴，误差 <= 2.0 deg | shoulder=0.000 deg, elbow=0.000 deg | 通过 | 主孔轴线必须与转轴方向一致。 |
| 肩部外凸台半径 | 18.000 mm | r=18.000, loc=(0.000, 17.000, -0.000), axis=(-0.000, 1.000, -0.000) | 通过 | 保留肩部承载区域。 |
| 肘部外凸台半径 | 16.500 mm | r=16.500, loc=(116.000, 17.000, -0.000), axis=(-0.000, 1.000, -0.000) | 通过 | 保留肘部承载区域。 |

## V3 装配孔系复核

| 检查项 | 设计要求 | 实测/检测结果 | 结论 | 作用 |
|---|---|---|---|---|
| 肘部 2x2 舵机安装孔 1 | Z 轴通孔 r=1.750 mm, x=98.050, y=-4.950 | r=1.750, loc=(98.050, -4.950, -22.000), axis=(0.000, 0.000, 1.000) | 通过 | 对应 V3 优化后的舵机/连接件安装孔。 |
| 肘部 2x2 舵机安装孔 2 | Z 轴通孔 r=1.750 mm, x=98.050, y=4.950 | r=1.750, loc=(98.050, 4.950, -22.000), axis=(0.000, 0.000, 1.000) | 通过 | 对应 V3 优化后的舵机/连接件安装孔。 |
| 肘部 2x2 舵机安装孔 3 | Z 轴通孔 r=1.750 mm, x=107.950, y=-4.950 | r=1.750, loc=(107.950, -4.950, -22.000), axis=(0.000, 0.000, 1.000) | 通过 | 对应 V3 优化后的舵机/连接件安装孔。 |
| 肘部 2x2 舵机安装孔 4 | Z 轴通孔 r=1.750 mm, x=107.950, y=4.950 | r=1.750, loc=(107.950, 4.950, -22.000), axis=(0.000, 0.000, 1.000) | 通过 | 对应 V3 优化后的舵机/连接件安装孔。 |
| 肩部侧向夹紧/定位孔 1 | Y 轴通孔 r=2.000 mm, x=-8.000, z=-10.500 | r=2.000, loc=(-8.000, 22.000, -10.500), axis=(-0.000, 1.000, -0.000) | 通过 | 对应肩部定位或夹紧接口。 |
| 肩部侧向夹紧/定位孔 2 | Y 轴通孔 r=2.000 mm, x=-8.000, z=10.500 | r=2.000, loc=(-8.000, 22.000, 10.500), axis=(-0.000, 1.000, -0.000) | 通过 | 对应肩部定位或夹紧接口。 |

## 结论

- V3 主关节接口复核：`PASS`。
- V3 装配孔系复核：`PASS`。
- V3 CAD 孔位复核总体：`PASS`。
- 本报告只确认 STEP 几何中的孔/轴/凸台特征存在；是否解决装配余量风险，需要看标准件装配检查报告。

## 输出文件

- 圆柱特征 CSV：`<repo>/05_improved_design/upper_arm_v3/mounting_check/upper_arm_v3_mounting_cylinders.csv`
- 结构化校核 JSON：`<repo>/05_improved_design/upper_arm_v3/mounting_check/upper_arm_v3_mounting_check.json`
- 中文报告：`<repo>/05_improved_design/upper_arm_v3/mounting_check/upper_arm_v3_mounting_check_report_zh.md`

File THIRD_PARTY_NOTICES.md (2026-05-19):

# Third-Party Notices

This portfolio project is built around the open-source SO-101 / SO-ARM100
robot arm resources and the `text-to-cad` CAD-as-code workflow.

- SO-101 / SO-ARM100 baseline CAD, STL, URDF and robot descriptions remain
  third-party upstream assets.
- `text-to-cad` is an external project used as the CAD-as-code inspiration and
  toolchain reference. Its local copy uses the MIT License.
- Generated V1/V2/V3 upper-arm CAD models, analysis scripts, Chinese reports,
  figures and CSV/JSON metrics in this repository are the portfolio work.

If this repository is used for public demonstration, keep upstream attribution
and check the current license of the original SO-101 project before reusing
official CAD/mesh files commercially.

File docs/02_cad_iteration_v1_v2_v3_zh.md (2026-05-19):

# SO-101 upper_arm_link Official / V1 / V2 / V3 总对比报告

## 这一步在做什么

Step 17 把 upper arm 这条线从 baseline、工作空间、静载力矩、CAD 重建、STEP 孔位校核、标准件装配检查到 URDF/PyBullet 回归，整理成一版完整作品集总稿。

## 为什么这一步重要

前面的单点结果已经足够证明每一版模型都“能做出来”，但作品集真正需要的是一条完整工程链：

1. 官方 baseline 能加载、能运动、能分析。
2. AI 辅助 CAD 能做出参数化版本。
3. STEP 特征级校核能发现真实装配问题。
4. URDF/PyBullet 回归能证明结构件改动没有破坏运动学。
5. 力矩回归能说明质量变化对机械性能的影响。

## 四版本核心指标

| 版本 | 角色 | 体积 mm^3 | PLA 质量 g | URDF screening 质量 kg | 相对官方体积变化 | 孔位/接口校核 | smoke 最大末端差 m | shoulder_lift p95 Nm | 相对官方变化 |
|---|---|---:|---:|---:|---:|---|---:|---:|---:|
| official | baseline | 117328.19 | 145.49 | 0.103000 | 0.00% | 官方基准 | 0.000000e+00 | 1.1422 | 0.00% |
| V1 | 轻量化概念版 | 93885.71 | 116.42 | 0.082420 | -19.98% | PASS / 关键装配未完全复现 | 0.000000e+00 | 1.1254 | -1.47% |
| V2 | 装配接口增强版 | 98626.10 | 122.30 | 0.086582 | -15.94% | PASS | 0.000000e+00 | 1.1288 | -1.17% |
| V3 | 孔系余量修正版 | 101891.50 | 126.35 | 0.089448 | -13.16% | PASS | 0.000000e+00 | 1.1313 | -0.95% |

## 设计迭代脉络

### Official

- 官方 SO-101 upper arm 作为真实开源 baseline，不改动。
- 作用是给后续所有改进提供统一参照系。

### V1

- 先做轻量化概念版，保留主关节中心距和接口轴线。
- 它证明 AI 辅助参数化建模可以把体积和惯量降下来。
- 但它还没有把完整装配接口补齐。

### V2

- 在 V1 上补齐肘部 2x2 安装孔、沉孔和肩部夹紧/定位孔。
- 它把 upper arm 从“概念件”推进到“装配表达更完整的结构件”。
- 但标准件装配检查仍暴露出肘部孔系余量偏紧。

### V3

- 针对 Step 14 的警告，移动肘部孔系并放宽孔径、沉孔和局部 pad。
- 结果是 V3 在 CAD 装配检查和 PyBullet smoke test 上都通过，且 100g payload 下 `shoulder_lift` p95 仍低于官方 baseline。

## 我学到的工程方法

- 不要只看 mesh 外观，要回到 STEP B-Rep 特征去验证孔位和轴线。
- 不要只做 CAD，要把 CAD 接回 URDF/PyBullet 验证运动链。
- 不要只看一版结果，要做同口径的 V1/V2/V3 对比。
- 不要默认 AI 生成结果是最终答案，要用工程脚本筛查和修正。

## 当前边界

- 现在 upper arm 这条线已经闭环，但还没有做真实 FEA、打印方向、螺钉预紧和实物装机。
- 目前惯量仍是 screening 值，不是最终材料标定。
- 还可以继续推进 lower arm、wrist 或完整整机对比。

## 模型图对比

- 整体等轴视图：`<repo>/06_portfolio_summary/model_visuals/upper_arm_official_v1_v2_v3_isometric.png`
- V1/V2/V3 三视图：`<repo>/06_portfolio_summary/model_visuals/upper_arm_v1_v2_v3_three_views.png`
- V2/V3 肘部孔系局部差异图：`<repo>/06_portfolio_summary/model_visuals/upper_arm_v2_v3_elbow_hole_zoom.png`
- 图片说明页：`<repo>/06_portfolio_summary/model_visuals/upper_arm_model_visual_comparison_zh.md`

这些图的作用是把“参数、孔位和力矩结果”转成直观可看的模型差异，说明 V1 先做轻量化，V2 补装配接口，V3 针对肘部孔系装配余量做修正。

## 有限元初步验证

已补充 Official / V3 upper arm 第一版静力有限元 screening：

- 报告：`<repo>/07_fea_analysis/upper_arm_static_fea/results/upper_arm_static_fea_report_zh.md`
- 应力图：`<repo>/07_fea_analysis/upper_arm_static_fea/results/upper_arm_static_fea_von_mises.png`
- 位移图：`<repo>/07_fea_analysis/upper_arm_static_fea/results/upper_arm_static_fea_displacement.png`

当前 FEA 结论是：V3 的可网格化 CAE 变体相对 official 仍然更轻，但在 10 N 向下载荷 screening 工况下，最大位移和最大 von Mises 应力高于 official；不过两者按 PLA 屈服强度估算的安全系数都很高。这个结果适合用于说明“轻量化需要通过 FEA 复核刚度和应力”，也为后续 V4 加强筋或局部加厚提供依据。

已进一步补充接口边界 FEA：

- 报告：`<repo>/07_fea_analysis/upper_arm_static_fea/results_interface_boundary/upper_arm_interface_fea_report_zh.md`
- 应力图：`<repo>/07_fea_analysis/upper_arm_static_fea/results_interface_boundary/upper_arm_interface_fea_von_mises.png`
- 位移图：`<repo>/07_fea_analysis/upper_arm_static_fea/results_interface_boundary/upper_arm_interface_fea_displacement.png`

接口边界工况下，V3 仍然更轻，最大位移仍高于 official，但最大 von Mises 应力低于 official。这个组合说明 V3 当前不是强度直接失效问题，而是轻量化后刚度不足更明显，后续 V4 应优先加强中部梁和肋板布局。

已补充 full V3 CAE 几何清理与完整孔系 FEA：

- CAE 清理诊断：`<repo>/07_fea_analysis/upper_arm_static_fea/cae_geometry_cleanup/upper_arm_v3_cae_geometry_cleanup_report_zh.md`
- full V3 clean FEA 报告：`<repo>/07_fea_analysis/upper_arm_static_fea/results_full_v3_clean/upper_arm_full_v3_clean_fea_report_zh.md`
- full V3 clean 应力图：`<repo>/07_fea_analysis/upper_arm_static_fea/results_full_v3_clean/upper_arm_full_v3_clean_fea_von_mises.png`
- full V3 clean 位移图：`<repo>/07_fea_analysis/upper_arm_static_fea/results_full_v3_clean/upper_arm_full_v3_clean_fea_displacement.png`

这一步解决了前面 full V3 无法直接体网格化的问题：7 mm 粗网格在小孔和沉孔附近会产生重叠边界面，改用 5 mm 精细网格后，保留 shoulder clamp holes、elbow mount through holes 和 counterbores 的 full V3 可以正常生成四面体网格。完整孔系 FEA 下，full V3 相对 official 质量降低 `11.51%`，但最大位移增加 `191.07%`，最大 von Mises 应力增加 `135.71%`，说明 V3 已经可以作为真实 CAE 输入，但下一版仍应优先补刚度。

## 下一步

Step 21 建议先在 full V3 clean mesh 上重跑接口边界 FEA，再基于完整孔系的应力/位移结果设计 `upper_arm_v4`。这样 V4 的加强位置不是凭感觉决定，而是由完整孔系 CAE 结果反推。

## 输出文件

- 关键指标 CSV：`<repo>/06_portfolio_summary/upper_arm_v1_v2_v3_key_metrics.csv`
- 汇总图：`<repo>/06_portfolio_summary/upper_arm_v1_v2_v3_summary_plot.png`
- 模型图对比说明页：`<repo>/06_portfolio_summary/model_visuals/upper_arm_model_visual_comparison_zh.md`
- FEA 报告：`<repo>/07_fea_analysis/upper_arm_static_fea/results/upper_arm_static_fea_report_zh.md`
- 接口边界 FEA 报告：`<repo>/07_fea_analysis/upper_arm_static_fea/results_interface_boundary/upper_arm_interface_fea_report_zh.md`
- full V3 clean FEA 报告：`<repo>/07_fea_analysis/upper_arm_static_fea/results_full_v3_clean/upper_arm_full_v3_clean_fea_report_zh.md`
- 总对比报告：`<repo>/06_portfolio_summary/upper_arm_v1_v2_v3_total_comparison_zh.md`
- upper arm 项目说明：`docs/upper_arm_v1_v2_v3_project_notes_zh.md`

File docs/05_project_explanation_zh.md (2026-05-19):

# SO-101 AI 辅助机械臂结构项目说明

## 项目概述

本项目基于开源 SO-101 follower arm，构建 AI 辅助机械结构改进流程。流程先复现官方 CAD/URDF，在 PyBullet 中验证 baseline，然后做工作空间、静载力矩和结构瓶颈分析，确定 `upper_arm_link` 是第一轮优化对象。之后使用 AI 辅助生成参数化 CAD V1，完成 STEP/STL 导出、URDF smoke test 和力矩对比；再用 STEP B-Rep 圆柱特征做孔位校核，发现 V1 装配孔系不足，于是迭代 V2，补充舵机安装孔、沉孔和肩部定位孔，并完成二级孔位校核和仿真验证。

## 重点数据

- 官方 upper arm 体积：117328.19 mm^3，PLA 粗估质量 145.49 g。
- V1 体积：93885.71 mm^3，相对官方约 -19.98%。
- V2 体积：98626.10 mm^3，相对官方约 -15.94%。
- V2 二级装配孔位校核：PASS。
- V2 接回 URDF 后，2001 个姿态最大末端位置差：0.000000e+00 m。
- 100g payload 下，官方 `shoulder_lift` p95：1.1440 Nm，V1：1.1268 Nm，V2：1.1303 Nm。

## 工程能力

- 开源机器人项目中的 CAD、STL、URDF 和仿真资源解析。
- 机械臂结构模块拆解、受力分析和结构瓶颈定位。
- AI 辅助参数化建模与 STEP 特征级孔位校核。
- CAD 结构件回接 URDF/PyBullet，并检查运动链是否被破坏。
- 设计取舍分析：V1 更轻，V2 更接近真实装配，V3 修正孔系余量。
- 建模问题记录与修复：V2 初版 pad 覆盖主孔，通过调整建模顺序解决。

## 当前边界

- 当前还不是生产级零件，后续需要标准件装配、干涉检查、FEA、打印方向和真实装机验证。
- 当前惯量是 screening 方法，按体积比例缩放 URDF 质量和惯量，不是最终材料标定。
- 当前 visual mesh 已接回 URDF，collision mesh 和完整物理接触仍需进一步完善。

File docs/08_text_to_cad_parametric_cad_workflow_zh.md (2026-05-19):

# Text-to-CAD机械结构参数化建模与工程校核流程

## 项目定位

本项目用于说明：AI 不是只生成一张机械臂外观图，而是参与“结构需求拆解、参数化建模、STEP/STL 导出、CAD 特征校核、装配检查、URDF 回归和 FEA 验证”的完整工程流程。

该模块的完整资料包位于：

- `projects/text_to_cad_parametric_cad/`

## 为什么做这一步

直接用 AI 生成 CAD 或 mesh 容易停留在外观层面，常见问题包括：

- 孔位、沉孔和装配接口不准确。
- 生成的模型不能可靠导出 STEP/STL。
- mesh 能看但不能做真实装配或有限元网格。
- 修改结构后无法证明机械臂 URDF 运动链仍然正确。

因此本项目把 Text-to-CAD 思路改造成可验证流程：AI 负责辅助提出结构方案、拆解参数和生成脚本，工程脚本负责 CAD 导出、孔位校核、装配检查和仿真验证。

## 技术路线

```mermaid
flowchart LR
  A["文本需求 / 结构目标"] --> B["AI 辅助参数拆解"]
  B --> C["build123d / OCP 参数化 CAD"]
  C --> D["STEP / STL 导出"]
  D --> E["STEP B-Rep 孔位与圆柱特征校核"]
  E --> F["标准件装配检查"]
  F --> G["URDF / PyBullet smoke test"]
  G --> H["Gmsh / CalculiX FEA 验证"]
  H --> I["下一版结构改进建议"]
```

## 在本项目中的实现

### 1. CAD 环境与仿真环境拆分

CAD 环境主要用于：

- `build123d`
- `OCP / OpenCascade`
- `FreeCADCmd`
- `Gmsh`
- STEP/STL 导出

仿真环境主要用于：

- `PyBullet`
- URDF 加载
- 工作空间采样
- 静载力矩估算
- 运动学 smoke test

这样做的原因是 CAD 内核、OpenCascade、PyBullet 和机器人学习依赖容易冲突。环境拆分后，CAD 生成和仿真验证可以各自稳定运行。

### 2. 参数化建模对象

第一阶段选取 SO-101 follower arm 的 `upper_arm_link`，因为它同时具备：

- 明确的机械臂结构功能。
- 与 shoulder / elbow 关节相关的装配接口。
- 对整机刚度、质量和静载力矩有明显影响。
- 适合做轻量化、孔位修正、肋板布局和有限元对比。

### 3. V1 / V2 / V3 迭代

| 版本 | 目标 | 主要变化 | 校核结果 |
|---|---|---|---|
| V1 | 轻量化概念重建 | 保留主关节中心距，建立基本梁体和主孔 | 能导出 STEP/STL，但关键装配接口不足 |
| V2 | 补齐装配接口 | 增加 M3 安装孔、沉孔、肩部夹紧/定位孔 | 装配表达更完整，但肘部孔系材料余量偏紧 |
| V3 | 修正孔系余量 | 调整肘部孔位、孔径、沉孔和局部 pad | 孔位复核 PASS，标准件装配检查 PASS |

## 工程校核方法

### STEP 特征级校核

不是只看 STL 外观，而是读取 STEP / B-Rep 中的圆柱面特征，检查：

- 主关节孔直径。
- M3 安装孔直径。
- 沉孔直径和深度。
- 孔轴方向。
- 孔中心距。
- 孔边材料余量。
- shoulder clamp 和 elbow mount 的装配接口。

相关数据位于：

- `data/cad/upper_arm_v1_mounting_check.json`
- `data/cad/upper_arm_v2_mounting_check.json`
- `data/cad/upper_arm_v3_mounting_check.json`
- `data/cad/upper_arm_v2_standard_part_checks.csv`
- `data/cad/upper_arm_v3_standard_part_checks.csv`

### URDF / PyBullet 回归

将改进后的 upper arm mesh 接回 URDF 后，进行 2001 个姿态的 smoke test，检查末端位置是否与 baseline 保持一致。V3 的最大末端位置差为 `0`，说明视觉 mesh 替换没有破坏机械臂原运动链。

相关代码位于：

- `src/cad/upper_arm_v1/upper_arm_v1_urdf_smoke.py`
- `src/cad/upper_arm_v2/upper_arm_v2_urdf_smoke.py`
- `src/cad/upper_arm_v3/upper_arm_v3_urdf_smoke.py`

### FEA 连接

Text-to-CAD 生成的结构不是最终结论，还需要进入 CAE。V3 在 full clean FEA 中可以用 5 mm 四面体网格完成 Gmsh / CalculiX 静力分析。

结论是：V3 质量降低，但刚度下降明显，后续 V4 需要加强中部梁、上下梁连接和肋板布局。

## 对应文件

CAD 脚本：

- `src/cad/upper_arm_v1/upper_arm_v1_cad.py`
- `src/cad/upper_arm_v2/upper_arm_v2_cad.py`
- `src/cad/upper_arm_v3/upper_arm_v3_cad.py`

模型文件：

- `models/upper_arm_v1/upper_arm_v1_ai_rebuild.step`
- `models/upper_arm_v2/upper_arm_v2_ai_rebuild.step`
- `models/upper_arm_v3/upper_arm_v3_ai_rebuild.step`

装配模型：

- `models/assemblies/upper_arm_v2_simplified_standard_parts_assembly.step`
- `models/assemblies/upper_arm_v3_simplified_standard_parts_assembly.step`

可视化图片：

- `figures/cad/upper_arm_official_v1_v2_v3_isometric.png`
- `figures/cad/upper_arm_v1_v2_v3_three_views.png`
- `figures/cad/upper_arm_v2_v3_elbow_hole_zoom.png`

## 工程说明

Text-to-CAD 在本项目中的定位不是直接输出最终零件，而是将自然语言结构需求转化为参数化 CAD 脚本，再通过 STEP/STL 导出、STEP B-Rep 特征校核、标准件装配检查、URDF/PyBullet 回归和 FEA 验证结果约束设计。该流程将 AI 生成结果纳入机械工程验证链路，避免模型只停留在外观层面。

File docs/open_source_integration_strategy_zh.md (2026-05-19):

# SO-101 项目开源栈整合与改进路线

## 为什么要调整路线

前面已经完成了 official baseline、upper arm V1/V2/V3、CAD 校核、URDF/PyBullet、FEA screening 和 full V3 CAE 几何清理。这个过程证明了我们能把一个结构件从 CAD 改到仿真验证，但还有一个明显短板：目前更多是自建脚本闭环，没有充分利用成熟开源项目的完整工程能力。

如果目标是机械/CAE/AI 结构方向实习作品集，后续主线应从“我自己写脚本做了一个机械臂零件”升级为：

> 基于 SO-101 开源机械臂，复现官方 CAD/URDF/仿真资产；整合 ROS2/MoveIt/LeRobot/CAE 开源工具链；用 AI 辅助做结构改进，并用运动学、装配、有限元和可视化结果验证改进效果。

## 当前已经做了什么

- 已使用 SO-ARM100/SO-101 官方项目中的 STEP、STL、URDF、MJCF 和 Simulation assets。
- 已复现官方 SO-101 follower arm 的 URDF 加载、关节解析、随机运动、工作空间和静载力矩分析。
- 已选定 `upper_arm_link` 作为第一轮结构改进对象。
- 已完成 V1/V2/V3 参数化 CAD 重建、STEP/STL 导出、孔位校核、标准件装配检查、URDF smoke test 和力矩回归。
- 已完成 official / V3 的初步 FEA、接口边界 FEA，以及 full V3 clean mesh 的完整孔系 FEA。

## 当前不足

- CAD 部分主要是基于 build123d/OCP 的局部重建，还没有形成“官方装配 -> 参数化改件 -> 自动回写机器人描述”的完整开源 CAD pipeline。
- 仿真部分主要用 PyBullet smoke test，还没有接入更完整的 ROS2 / MoveIt / Rerun / Foxglove 等可视化和运动规划栈。
- FEA 部分目前是自建线性静力 screening solver，适合学习和快速对比，但不够像工业 CAE 工作流；后续应接入 Gmsh + CalculiX/FreeCAD FEM，生成 `.inp`、求解结果和 ParaView/VTK 后处理。
- 项目叙事还没有突出“我整合了哪些开源系统，并在其基础上做了结构优化”。

## 推荐整合的开源项目

| 角色 | 推荐项目 | 用在本项目中的作用 |
|---|---|---|
| 官方机械臂 baseline | `TheRobotStudio/SO-ARM100` | 保留为唯一 baseline 来源：CAD、STL、URDF、MJCF、装配说明、BOM。 |
| 机器人学习生态 | `huggingface/lerobot` | 作为 SO-101 的 AI/机器人学习上层生态，后续展示模仿学习或策略控制接口。 |
| ROS2 + MoveIt + Rerun | `legalaspro/so101-ros-physical-ai` | 用来补齐可视化、运动规划、真实/仿真机器人数据流，让项目不止停留在单个 PyBullet smoke test。 |
| CAD 到机器人描述 | `Rhoban/onshape-to-robot` | 用来对齐官方“CAD -> URDF/MJCF”思想，后续可研究如何把改进件更规范地接回机器人描述。 |
| CAD as code | `build123d` / `CadQuery` / 当前 `text-to-cad` | 继续用于 AI 辅助参数化结构改进，但要把它放进开源 pipeline，而不是单独存在。 |
| 网格与 CAE | `Gmsh` + `CalculiX` / `FreeCAD FEM` | 把 FEA 从自建 screening 升级为更接近真实 CAE 的开源求解流程。 |
| 结果后处理 | `meshio` / `PyVista` / `ParaView` | 输出 VTK/VTU、应力云图、位移云图，便于作品集展示。 |

## 新项目主线

### 阶段 A：开源项目复现

目标：不是马上改结构，而是证明我能复现并理解完整开源机械臂工程。

要做：
- 复现 SO-ARM100/SO-101 官方 CAD、STL、URDF、MJCF 和 Simulation assets。
- 建立 source snapshot，不直接改官方文件。
- 记录官方项目结构、装配模块、每个 link 的机械作用。
- 用 PyBullet 或 ROS2 加载官方 URDF，输出关节表、质量表、运动范围和工作空间。

产出：
- 官方资源清单。
- 官方结构模块拆解。
- 官方 URDF/运动学验证报告。
- 官方 baseline 可视化图。

### 阶段 B：开源仿真与可视化栈整合

目标：把项目从“能加载 URDF”提升到“能在成熟工具中看运动、看轨迹、看规划”。

要做：
- 优先复现 `so101-ros-physical-ai` 中的 ROS2/MoveIt/Rerun 工作流。
- 将官方 SO-101 URDF 接入 MoveIt planning scene。
- 导出或记录轨迹、关节角、末端路径。
- 后续将 V3/V4 改进件替换到 URDF 中，比较可视化运动效果。

产出：
- ROS2/MoveIt/Rerun 复现报告。
- 官方模型运动轨迹图。
- 改进模型接回仿真栈的对比图。

### 阶段 C：开源 CAE 工具链升级

目标：把当前 FEA screening 升级为更像工业岗位的开源 CAE 流程。

要做：
- 使用 Gmsh 负责 STEP/B-Rep 体网格。
- 使用 CalculiX 或 FreeCAD FEM 负责线性静力求解。
- 生成 `.inp` 求解文件、`.frd/.dat` 或等效结果文件。
- 用 meshio/PyVista/ParaView 做后处理。
- 保留当前自建 solver 作为快速 screening，对比开源求解器结果。

产出：
- official / V3 / V4 的 CalculiX 输入文件。
- official / V3 / V4 的应力、位移和安全系数结果。
- 网格收敛性检查：例如 7 mm、5 mm、3 mm 对比。

### 阶段 D：AI 辅助结构改进

目标：AI 不只是画模型，而是参与“问题定位 -> 结构方案 -> 参数化建模 -> 仿真验证 -> 迭代”的闭环。

要做：
- 根据 FEA 和运动学结果定位问题：V3 更轻，但刚度不足。
- 让 AI 生成 V4 设计约束：加强中部梁、上下梁连接、肋板布局，保留接口孔位。
- 用 build123d/text-to-cad 实现参数化 V4。
- 自动导出 STEP/STL。
- 自动跑 CAD 孔位检查、标准件装配检查、URDF smoke、力矩回归、FEA。

产出：
- V4 参数化 CAD 源码。
- V4 STEP/STL/URDF 替换件。
- official / V3 / V4 对比报告。
- 结构改进前后图、应力图、位移图、质量和安全系数表。

## 现在最应该做的下一步

下一步不急着继续 V4，而是做：

> Step 21：开源项目整合审计与复现计划。

具体做三件事：

1. 在服务器建立 `08_open_source_integration/`，记录已使用和待整合的开源项目。
2. 对 `SO-ARM100`、`LeRobot`、`so101-ros-physical-ai`、`onshape-to-robot`、`Gmsh/CalculiX` 做可运行性检查。
3. 决定后续主线：先复现 ROS2/MoveIt/Rerun 可视化栈，再把 V3/V4 改进件接进去；FEA 同时从自建 solver 升级到 CalculiX/FreeCAD FEM。

## 工程流程说明

本项目选择 SO-101 开源机械臂作为 baseline。第一阶段复现其 CAD、URDF 和仿真资源；第二阶段用 AI 辅助对 upper arm 做参数化重建和结构轻量化；第三阶段发现轻量化带来装配孔余量和刚度问题，于是用 CAD 特征校核、标准件检查和有限元结果迭代到 V3；下一阶段计划升级为开源栈整合，接入 ROS2/MoveIt/Rerun 和 CalculiX/FreeCAD FEM，使结构改进能在更完整的机器人仿真和 CAE 流程中验证。

这一路线强调开源工程复现、工具链整合、结构优化和验证闭环，而不是停留在“用 AI 生成外观模型”。

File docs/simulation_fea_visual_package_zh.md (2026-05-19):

# SO-101 仿真与有限元分析图包

## 这一步在做什么

本步骤把前面已经完成的 CAD 建模、机器人仿真、工作空间分析、静载力矩分析、FEA 前处理、CalculiX 求解和结果云图整理成一组工程说明图片。

目标不是新增一个单独数值，而是增强项目说服力：让别人一眼看到“模型从哪里来、怎么改、怎么接回仿真、有限元怎么建模、结果如何指导下一轮设计”。

## 生成图片

### 1. 仿真与有限元证据总览

SO-101 仿真与有限元证据总览

用途：总览图，适合放在项目汇报第一页，说明项目覆盖了 baseline 复现、运动仿真、结构分析、CAD 迭代和 FEA。

### 2. AI 辅助 CAD 建模与结构迭代

AI 辅助 CAD 建模与结构迭代

用途：说明 upper_arm 不是一次性生成，而是经历 V1 轻量化、V2 装配孔补全、V3 孔系余量修正。

### 3. 有限元前处理建模图

有限元前处理建模图

用途：回答“有限元怎么建模”。图中明确展示了网格、固定端、加载端、10 N 载荷方向、材料和求解器链路。

### 4. 有限元结果图

有限元结果图

用途：展示应力云图和位移云图。核心结论是 V3 轻量化有效，但刚度下降明显，V4 应该做局部加强。

### 5. 开源仿真与 CAE 工作流

开源仿真与 CAE 工作流

用途：说明项目不是孤立脚本，而是开源 CAD/URDF/PyBullet/Gmsh/CalculiX 的组合工程流程。

## 工程流程说明

流程先复现官方 SO-101 的 URDF 和 PyBullet 仿真，确认关节链和末端运动正常；然后用工作空间和静载力矩分析定位结构瓶颈，确定 upper_arm 是第一轮改进对象。之后使用 AI 辅助参数化 CAD 重建，经历 V1、V2、V3 三轮迭代，并把改进件接回 URDF 做运动学回归。最后将 official 和 full V3 的 STEP 几何转成 Gmsh 四面体网格，再导出 CalculiX 输入文件做静力有限元，得到应力和位移对比。结果显示 V3 质量降低，但刚度下降，所以下一版 V4 的目标不是继续减重，而是加强中部梁、上下梁连接和肋板布局。

## 当前边界

- 当前 FEA 是线性静力 screening，不是最终强度认证。
- 当前边界条件为节点集合固定/加载，还没有做真实螺钉接触、轴承接触和预紧。
- 当前材料为 PLA screening 参数，后续可以加入打印方向、层间强度和材料各向异性。
- 当前图包已经足够支撑阶段性工程说明，但后续 V4 应增加“改进前后 FEA 云图对比”和“网格收敛图”。

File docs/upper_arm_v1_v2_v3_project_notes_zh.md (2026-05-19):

# SO-101 upper arm Official / V1 / V2 / V3 项目说明

## 项目概述

本项目基于开源 SO-101 follower arm，先复现官方 baseline，再做工作空间、静载力矩和结构瓶颈分析，确定 upper arm 是第一轮优化对象。随后使用 AI 辅助生成参数化 CAD，完成 V1 轻量化、V2 装配接口增强、V3 孔系余量修正三轮迭代，并把每一版都接回 STEP 校核和 URDF/PyBullet 验证。

## 工程链路

项目不是只生成一个外观模型，而是围绕真实开源机械臂做工程闭环：官方 baseline 能加载、能运动、能分析；V1 先把 upper arm 做轻；V2 补上舵机孔、沉孔和肩部夹紧孔，让它更接近真实可装配结构；V3 针对装配检查中暴露的孔系余量问题再次修正。最后将 V3 接回 URDF/PyBullet，确认关节链和末端运动学没有被破坏，并用同口径静载力矩对比检查 `shoulder_lift` 负担变化。

## 工程能力

- 开源机器人项目拆解为 CAD、URDF、工作空间、力矩和装配接口几个层次。
- AI 辅助参数化建模和工程脚本校核结合。
- STEP 特征级孔位校核和装配风险定位。
- CAD 结果回接仿真，做同口径运动学和力矩回归。
- 设计取舍分析：V1 更轻，V2 更完整，V3 更可靠。

## 三个关键数字

- 官方 upper arm 体积：117328.19 mm^3。
- V1 / V2 / V3 体积：93885.71 / 98626.10 / 101891.50 mm^3。
- 100g payload 下 `shoulder_lift` p95：官方 1.1422 Nm，V1 1.1254 Nm，V2 1.1288 Nm，V3 1.1313 Nm。

## 当前边界

- 目前还没有做真实 FEA、打印方向、螺钉预紧和实物装机。
- 目前惯量是 screening 值，不是最终材料标定。
- 这条 upper arm 线已经完成闭环，下一步可以把同样方法复制到 lower arm。

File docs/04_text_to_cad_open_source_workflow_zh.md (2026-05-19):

# text-to-cad 与开源工具链整合说明

## 为什么引入 text-to-cad

本项目不是简单手工改一个 STL，而是希望形成“AI 提示词 / 参数化脚本 / CAD 文件 / URDF / FEA”的链路。`text-to-cad` 的价值在于提供 CAD-as-code 思路：把自然语言设计意图转成可编辑、可复用、可导出的建模脚本。

## 在本项目中的角色

- 用 AI 辅助梳理 upper arm 的结构参数、孔位和装配关系。
- 用 Python 参数化脚本表达 V1/V2/V3 的结构版本。
- 输出 STEP/STL，进入后续 CAD 校核、URDF smoke test 和 FEA。
- 将 AI 生成从“外观模型”推进到“可验证工程模型”。

## 工具链拆分

项目采用两个环境：

- CAD 环境：`build123d / OCP / Gmsh / meshio`，负责建模、STEP/STL 导出和网格处理。
- 仿真环境：`PyBullet / numpy / scipy / matplotlib`，负责 baseline 验证、工作空间和力矩分析。

拆分环境的原因是 CAD 内核、OpenCascade、PyBullet 和机器人学习依赖容易冲突。把 CAD 和仿真环境分开，更接近真实工程项目中的工具链管理方式。

## 目前边界

当前 text-to-cad 不是直接“一句话生成最终机械臂”，而是参与结构方案生成、参数化脚本编写和流程组织。最终结果仍由 STEP 特征、装配孔位、URDF 回归和 FEA 结果验证。

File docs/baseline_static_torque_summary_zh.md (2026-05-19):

# SO-101 官方 Baseline 静载关节力矩分析

## 目的

本报告用于估算官方 SO-101 Follower 在未进行 AI 辅助结构改进前的静载关节力矩需求。

## 数据来源与假设

- URDF：`<repo>/00_source_snapshot/Simulation_SO101/so101_new_calib.urdf`
- 末端负载作用点：`gripper_frame_link`
- 采样主关节：`shoulder_pan`、`shoulder_lift`、`elbow_flex`、`wrist_flex`、`wrist_roll`
- PyBullet 逆动力学使用的活动关节：`shoulder_pan`、`shoulder_lift`、`elbow_flex`、`wrist_flex`、`wrist_roll`、`gripper`
- 随机静态姿态数量：10000
- 重力加速度：9.81 m/s^2
- 末端 payload：0.00 kg、0.05 kg、0.10 kg、0.20 kg
- 主要展示 payload：0.10 kg

计算方法：

- 机械臂自身重力力矩：使用 PyBullet inverse dynamics，令 `qdot=0`、`qddot=0`。
- 末端 payload 力矩：把 payload 视为作用在末端的竖直向下外力，通过 `-J^T F` 换算到各关节。
- 本结果是静载估算，不包括加速度力矩、摩擦、线束拖拽、接触冲击、舵机热衰减和厂家完整力矩曲线。

## 力矩统计

| payload kg | 关节 | 最大绝对力矩 Nm | 95 分位绝对力矩 Nm | 平均绝对力矩 Nm | RMS Nm |
|---:|---|---:|---:|---:|---:|
| 0.00 | shoulder_pan | 0.0000 | 0.0000 | 0.0000 | 0.0000 |
| 0.00 | shoulder_lift | 0.8630 | 0.7950 | 0.3712 | 0.4482 |
| 0.00 | elbow_flex | 0.4529 | 0.4379 | 0.2650 | 0.2951 |
| 0.00 | wrist_flex | 0.1171 | 0.1167 | 0.0739 | 0.0822 |
| 0.00 | wrist_roll | 0.0024 | 0.0022 | 0.0010 | 0.0012 |
| 0.05 | shoulder_pan | 0.0000 | 0.0000 | 0.0000 | 0.0000 |
| 0.05 | shoulder_lift | 1.0640 | 0.9714 | 0.4522 | 0.5461 |
| 0.05 | elbow_flex | 0.5972 | 0.5758 | 0.3438 | 0.3835 |
| 0.05 | wrist_flex | 0.1952 | 0.1946 | 0.1232 | 0.1371 |
| 0.05 | wrist_roll | 0.0015 | 0.0014 | 0.0007 | 0.0008 |
| 0.10 | shoulder_pan | 0.0000 | 0.0000 | 0.0000 | 0.0000 |
| 0.10 | shoulder_lift | 1.2649 | 1.1496 | 0.5365 | 0.6462 |
| 0.10 | elbow_flex | 0.7415 | 0.7142 | 0.4235 | 0.4730 |
| 0.10 | wrist_flex | 0.2733 | 0.2725 | 0.1725 | 0.1920 |
| 0.10 | wrist_roll | 0.0054 | 0.0050 | 0.0024 | 0.0028 |
| 0.20 | shoulder_pan | 0.0000 | 0.0000 | 0.0000 | 0.0000 |
| 0.20 | shoulder_lift | 1.6669 | 1.5085 | 0.7100 | 0.8498 |
| 0.20 | elbow_flex | 1.0302 | 0.9917 | 0.5842 | 0.6533 |
| 0.20 | wrist_flex | 0.4297 | 0.4283 | 0.2712 | 0.3018 |
| 0.20 | wrist_roll | 0.0131 | 0.0122 | 0.0058 | 0.0069 |

## 0.10 kg Payload 下的主要结论

- 95 分位力矩最高的关节：`shoulder_lift` = 1.1496 Nm。
- 采样峰值力矩最高的关节：`shoulder_lift` = 1.2649 Nm。
- 采样水平半径范围：0.001 到 0.477 m。
- 采样末端 z 范围：-0.221 到 0.526 m。

## 工程解释

- 静载重力主要影响 pitch 链路关节：`shoulder_lift`、`elbow_flex`、`wrist_flex`。
- `shoulder_pan` 的轴线接近竖直，因此不是重力静载瓶颈；它更影响水平转向动态性能和底座刚度。
- 远端质量会放大上游关节力矩。减轻腕部、夹爪和下臂质量通常可以降低肩部和肘部负担。
- 第一轮 AI 辅助结构改进应优先考虑 upper arm、lower arm、wrist/gripper 和 base fixture，同时保留官方关节轴线和连杆长度。

## 生成文件

- `04_structural_analysis/baseline_static_torque_samples.csv`
- `04_structural_analysis/baseline_static_torque_plot.png`
- `04_structural_analysis/baseline_static_torque_summary.md`
- `04_structural_analysis/baseline_static_torque_summary_zh.md`

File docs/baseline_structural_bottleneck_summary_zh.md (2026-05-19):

# SO-101 结构瓶颈与简化梁应力分析

## 目的

本报告把官方 SO-101 Follower 的静载力矩分析结果转化为结构改进优先级，为后续 AI 辅助 CAD 重建提供依据。

## 数据来源

- URDF：`<repo>/00_source_snapshot/Simulation_SO101/so101_new_calib.urdf`
- 力矩采样数据：`<repo>/04_structural_analysis/baseline_static_torque_samples.csv`
- 结构筛查使用 payload：0.10 kg
- 假设打印塑料弹性模量：2.00 GPa
- 风险索引用参考许用应力：20.0 MPa

## 方法与限制

- 把每个结构模块近似为弱截面处的空心矩形悬臂梁。
- 弯矩来自 Step 6 静载关节力矩分析中的控制关节。
- 本结果是工程筛查模型，不是有限元仿真，也不是强度认证。
- 绝对应力值会受到打印方向、材料、层间结合、局部螺丝柱、圆角、真实壁厚和线槽影响。
- 本报告最有价值的部分是相对优先级和 AI 重建设计约束。

## 结构瓶颈优先级

| 排名 | 模块 | 控制关节 | 风险分数 | p95 弯矩 Nm | 峰值弯矩 Nm | p95 应力 MPa | p95 转角 deg | 第一轮改进方向 |
|---:|---|---|---:|---:|---:|---:|---:|---|
| 1 | upper_arm_link | shoulder_lift | 100.0 | 1.1496 | 1.2649 | 4.003 | 2.660 | 通过加强筋、盒式截面和线槽提高弱轴刚度，同时不移动肩部和肘部关节 frame。 |
| 2 | lower_arm_link | elbow_flex | 73.4 | 0.7142 | 0.7415 | 2.790 | 2.158 | 降低远端质量，并在腕部电机座和线束应力释放区域增加局部加强。 |
| 3 | wrist_gripper_module | wrist_flex | 53.2 | 0.2725 | 0.2733 | 1.889 | 2.194 | 降低远端质量，增加紧凑局部加强筋，并加入可换指尖或小型工具法兰。 |

## 主要结论

- 最高优先级结构件：`upper_arm_link`。
- 原因：它同时承受最高上游力矩、较大下游质量，并且肩部/肘部接口约束关键。
- 在假设截面下，简化应力值并不高；但真实工程风险更多来自局部螺丝柱、打印层方向、薄壁区域、线槽削弱和远端质量。

## 设计启示

- 第一轮 AI 重建设计不要改变官方关节轴线和连杆长度。
- CAD 改进重点应放在加强筋、局部盒式截面、线束通道、避开关节柱的轻量化孔和远端减重。
- base 的改进重点不是 shoulder_pan 的重力力矩，而是桌面安装面积、防倾覆和固定方式。
- CAD 重建后必须重新跑工作空间、力矩和 PyBullet 加载检查，再说明是否真正改进。

## 生成文件

- `04_structural_analysis/baseline_beam_stress_estimate.csv`
- `04_structural_analysis/baseline_structural_bottleneck_plot.png`
- `04_structural_analysis/baseline_structural_bottleneck_summary.md`
- `04_structural_analysis/baseline_structural_bottleneck_summary_zh.md`
- `04_structural_analysis/ai_structural_redesign_brief.md`
- `04_structural_analysis/ai_structural_redesign_brief_zh.md`

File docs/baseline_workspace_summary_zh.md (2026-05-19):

# SO-101 官方 Baseline 工作空间与任务区域可达性分析

## 目的

本报告用于量化官方 SO-101 Follower 在未进行任何 AI 辅助重建或结构改进前的工作空间表现。

## 数据来源

- URDF：`<repo>/00_source_snapshot/Simulation_SO101/so101_new_calib.urdf`
- 末端执行器参考点：`gripper_frame_link`
- 采样主关节：`shoulder_pan`、`shoulder_lift`、`elbow_flex`、`wrist_flex`、`wrist_roll`
- 随机采样姿态数量：30000

## 工作空间统计

- x 方向范围：-0.334 到 0.477 m
- y 方向范围：-0.438 到 0.437 m
- z 方向范围：-0.221 到 0.527 m
- 水平半径范围：0.002 到 0.477 m
- 0.025 m 分辨率下占用体素数量：11935
- 近似采样工作空间体积：0.18648 m^3

## 桌面任务区域可达性

设定桌面任务区域：

- x：0.15 到 0.40 m
- y：-0.25 到 0.25 m
- z：0.02 到 0.35 m
- 最近点距离阈值：0.035 m

结果：

- 估计可达目标比例：0.998，约 99.8%
- 平均最近采样距离：0.0124 m
- 95 分位最近采样距离：0.0201 m

## 工程解释

- 这是官方 SO-101 的几何工作空间 baseline，后续 AI 重建版和结构改进版都需要与它对比。
- 如果改进版结构明显缩小工作空间，就必须说明换来了什么收益，例如更高刚度、更低质量或更低力矩。
- 当前设定的桌面抓取/操作任务区域基本可以被官方 SO-101 覆盖，因此第一轮结构改进不应改变主关节轴线和连杆长度。

## 生成文件

- `04_structural_analysis/baseline_workspace_points.csv`
- `04_structural_analysis/baseline_workspace_plot.png`
- `04_structural_analysis/baseline_workspace_summary.md`
- `04_structural_analysis/baseline_workspace_summary_zh.md`

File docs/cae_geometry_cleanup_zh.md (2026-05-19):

# upper_arm_v3 CAE 几何清理诊断报告

## 这一步在做什么

Step 20 不做 V4，而是先清理和诊断 V3 的 CAE 几何。目标是回答一个明确问题：为什么 full V3 带小装配孔和沉孔时不能稳定生成四面体网格。

## 诊断方法

- 保持 V3 主体、梁、肋板、减重孔和主关节孔不变。
- 将小特征拆成不同组合测试：肩部夹紧孔、肘部安装通孔、肘部沉孔、完整孔系。
- 对每个组合分别测试两种布尔策略：一次性融合 cutter 后切除、逐个 cutter 顺序切除。
- 每种策略再测试是否进行 OpenCASCADE healing。

## 结论

- 7 mm 目标网格下，full V3 以及任何带小装配孔/沉孔的组合都会失败，失败集中表现为 `overlapping facets` 或 `segment and facet intersect`。
- 补充网格尺寸扫描后，full V3 完整孔系在 5.0 mm 目标网格下已经可以稳定生成四面体网格。
- 因此这次问题不是 full V3 几何完全不可用，而是小孔、沉孔、薄壁附近的局部特征尺寸小于 7 mm 粗网格能够可靠表达的尺度。
- CAE 清理策略从“删除小孔跑通”改为“保留完整孔系，并使用更合理的精细网格控制”。

## full V3 失败摘要

- `full_mount_features_fused_noheal`：Invalid boundary mesh (overlapping facets) on surface 141 surface 141
- `full_mount_features_fused_heal`：Invalid boundary mesh (overlapping facets) on surface 2 surface 2
- `full_mount_features_sequential_noheal`：Invalid boundary mesh (overlapping facets) on surface 140 surface 140
- `full_mount_features_sequential_heal`：Invalid boundary mesh (overlapping facets) on surface 72 surface 72

## 补充网格尺寸扫描

在 7 mm 诊断失败后，对 full V3 完整孔系继续做目标网格尺寸扫描。结果显示：

- 5.0 mm 目标网格：`PASS`
- 节点数：`3255`
- 四面体单元数：`11048`
- 输出 STEP：`<repo>/07_fea_analysis/upper_arm_static_fea/results_full_v3_clean/v3_full_cae_clean_5mm.step`

这说明 full V3 的 shoulder clamp holes、elbow mount through holes 和 counterbores 可以保留进入 CAE。真正需要清理的是网格策略：小孔和沉孔附近不能继续使用 7 mm 粗网格，否则体网格器会把相邻边界面表达成重叠或相交。

## 完整 full V3 clean FEA 结果

基于 5.0 mm 网格，已经重新对 official 和 full V3 做同口径静力 FEA：

| 版本 | 网格尺寸 mm | 节点 | 四面体 | 质量 g | 最大位移 mm | 最大 von Mises MPa | 安全系数 |
|---|---:|---:|---:|---:|---:|---:|---:|
| official | 5.0 | 3750 | 12410 | 144.07 | 0.024591 | 0.327 | 153.11 |
| full V3 | 5.0 | 3255 | 11048 | 127.49 | 0.071577 | 0.770 | 64.96 |

对比 official，full V3 在完整孔/沉孔保留后仍减重 `11.51%`，但最大位移增加 `191.07%`，最大 von Mises 应力增加 `135.71%`。这说明 V3 的装配几何已经可以进入 CAE，但结构刚度仍弱于 official，后续 V4 应以加强中部梁、上下梁连接和肋板布局为目标。

## 全部尝试结果

| 尝试 | 状态 | 肩部夹紧孔 | 肘部安装孔 | 沉孔 | 布尔策略 | healing | 节点 | 四面体 | 失败原因 |
|---|---|---|---|---|---|---|---:|---:|---|
| core_fused_noheal | PASS | False | False | False | fused | False | 1759 | 5620 |  |
| shoulder_clamp_only_fused_noheal | FAIL | True | False | False | fused | False | 0 | 0 | PLC Error:  A segment and a facet intersect at point |
| elbow_through_only_fused_noheal | FAIL | False | True | False | fused | False | 0 | 0 | Invalid boundary mesh (overlapping facets) on surface 59 surface 59 |
| elbow_with_counterbores_fused_noheal | FAIL | False | True | True | fused | False | 0 | 0 | Invalid boundary mesh (overlapping facets) on surface 135 surface 135 |
| all_mount_no_counterbores_fused_noheal | FAIL | True | True | False | fused | False | 0 | 0 | Invalid boundary mesh (overlapping facets) on surface 59 surface 59 |
| full_mount_features_fused_noheal | FAIL | True | True | True | fused | False | 0 | 0 | Invalid boundary mesh (overlapping facets) on surface 141 surface 141 |
| core_fused_heal | PASS | False | False | False | fused | True | 1758 | 5614 |  |
| shoulder_clamp_only_fused_heal | FAIL | True | False | False | fused | True | 0 | 0 | Invalid boundary mesh (overlapping facets) on surface 67 surface 67 |
| elbow_through_only_fused_heal | FAIL | False | True | False | fused | True | 0 | 0 | Invalid boundary mesh (overlapping facets) on surface 59 surface 59 |
| elbow_with_counterbores_fused_heal | FAIL | False | True | True | fused | True | 0 | 0 | Invalid boundary mesh (overlapping facets) on surface 2 surface 2 |
| all_mount_no_counterbores_fused_heal | FAIL | True | True | False | fused | True | 0 | 0 | Invalid boundary mesh (overlapping facets) on surface 59 surface 59 |
| full_mount_features_fused_heal | FAIL | True | True | True | fused | True | 0 | 0 | Invalid boundary mesh (overlapping facets) on surface 2 surface 2 |
| core_sequential_noheal | PASS | False | False | False | sequential | False | 1759 | 5621 |  |
| shoulder_clamp_only_sequential_noheal | FAIL | True | False | False | sequential | False | 0 | 0 | PLC Error:  A segment and a facet intersect at point |
| elbow_through_only_sequential_noheal | FAIL | False | True | False | sequential | False | 0 | 0 | Invalid boundary mesh (overlapping facets) on surface 59 surface 59 |
| elbow_with_counterbores_sequential_noheal | FAIL | False | True | True | sequential | False | 0 | 0 | Invalid boundary mesh (overlapping facets) on surface 138 surface 138 |
| all_mount_no_counterbores_sequential_noheal | FAIL | True | True | False | sequential | False | 0 | 0 | Invalid boundary mesh (overlapping facets) on surface 59 surface 59 |
| full_mount_features_sequential_noheal | FAIL | True | True | True | sequential | False | 0 | 0 | Invalid boundary mesh (overlapping facets) on surface 140 surface 140 |
| core_sequential_heal | PASS | False | False | False | sequential | True | 1758 | 5614 |  |
| shoulder_clamp_only_sequential_heal | FAIL | True | False | False | sequential | True | 0 | 0 | Invalid boundary mesh (overlapping facets) on surface 67 surface 67 |
| elbow_through_only_sequential_heal | FAIL | False | True | False | sequential | True | 0 | 0 | Invalid boundary mesh (overlapping facets) on surface 59 surface 59 |
| elbow_with_counterbores_sequential_heal | FAIL | False | True | True | sequential | True | 0 | 0 | Invalid boundary mesh (overlapping facets) on surface 138 surface 138 |
| all_mount_no_counterbores_sequential_heal | FAIL | True | True | False | sequential | True | 0 | 0 | Invalid boundary mesh (overlapping facets) on surface 59 surface 59 |
| full_mount_features_sequential_heal | FAIL | True | True | True | sequential | True | 0 | 0 | Invalid boundary mesh (overlapping facets) on surface 72 surface 72 |

## 输出文件

- 诊断 CSV：`<repo>/07_fea_analysis/upper_arm_static_fea/cae_geometry_cleanup/upper_arm_v3_cae_geometry_cleanup_matrix.csv`
- 诊断目录：`<repo>/07_fea_analysis/upper_arm_static_fea/cae_geometry_cleanup`
- full V3 clean FEA 报告：`<repo>/07_fea_analysis/upper_arm_static_fea/results_full_v3_clean/upper_arm_full_v3_clean_fea_report_zh.md`
- full V3 clean 应力图：`<repo>/07_fea_analysis/upper_arm_static_fea/results_full_v3_clean/upper_arm_full_v3_clean_fea_von_mises.png`
- full V3 clean 位移图：`<repo>/07_fea_analysis/upper_arm_static_fea/results_full_v3_clean/upper_arm_full_v3_clean_fea_displacement.png`

## 当前边界

- 这一步是 CAE 前处理诊断，不是最终强度结论。
- 5 mm 精细网格已经解决 full V3 的体网格问题，但当前边界条件仍是 screening 工况，不等于真实螺钉接触、轴承接触、预紧和打印各向异性验证。
- 下一步建议在 full V3 clean mesh 上重跑接口边界 FEA，再基于 full V3 的真实孔系结果设计 `upper_arm_v4`。

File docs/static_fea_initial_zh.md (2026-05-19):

# SO-101 upper_arm_link Official / V3 静力有限元初步对比

## 这一步在做什么

Step 18 对官方 upper arm 和 AI 改进后的 V3 upper arm 建立相同的线性静力有限元工况，用同一套材料、网格尺寸、固定区域和载荷区域对比结构性能。

## 工况设定

- 几何对象：`official` 使用官方 STEP；`V3` 使用根据 V3 参数在 Gmsh/OpenCASCADE 中重建的 CAE 几何。
- 单位体系：mm、N、MPa。
- 材料：PLA screening，弹性模量 2500 MPa，泊松比 0.35，屈服强度按 50 MPa 做 screening。
- 约束：固定 shoulder 侧沿零件最长方向前 12% 区域的全部平动自由度。
- 载荷：在 elbow 侧沿零件最长方向后 10% 区域施加合力 10.0 N，方向为 Z 负方向。
- 网格：Gmsh 四面体网格，目标尺寸 7.0 mm。

## 核心结果

| 版本 | 几何 | 主轴 | 节点数 | 四面体数 | 网格体积 mm^3 | 估算质量 g | 最大位移 mm | 最大 von Mises MPa | p95 von Mises MPa | 屈服安全系数 |
|---|---|---|---:|---:|---:|---:|---:|---:|---:|---:|
| official | step | x | 2845 | 8943 | 115465.86 | 143.18 | 0.023253 | 0.324 | 0.134 | 154.21 |
| V3 | gmsh_occ_parametric_no_small_mount_holes | x | 1759 | 5620 | 104561.17 | 129.66 | 0.069782 | 0.588 | 0.356 | 85.02 |

## 对比结论

- V3 相对 official 的网格体积/估算质量变化：-9.44%。
- V3 相对 official 的最大位移变化：+200.10%。
- V3 相对 official 的最大 von Mises 应力变化：+81.37%。
- V3 当前可网格化 CAE 变体为 `gmsh_occ_parametric_no_small_mount_holes`。full V3 和去沉孔版本在体网格阶段暴露出重叠边界问题，说明后续需要继续做 CAD/CAE 几何清理；本轮先保留主体、减重孔和主关节孔，暂时去掉小装配孔来完成第一版强度 screening。
- 这一步把前面的 CAD 改进从“几何与运动学验证”推进到“结构强度 screening 验证”。

## 输出文件

- 指标 JSON：`<repo>/07_fea_analysis/upper_arm_static_fea/results/upper_arm_static_fea_metrics.json`
- 指标 CSV：`<repo>/07_fea_analysis/upper_arm_static_fea/results/upper_arm_static_fea_metrics.csv`
- official VTK：`<repo>/07_fea_analysis/upper_arm_static_fea/results/official_upper_arm_static_fea.vtu`
- V3 VTK：`<repo>/07_fea_analysis/upper_arm_static_fea/results/v3_upper_arm_static_fea.vtu`
- 应力图：`<repo>/07_fea_analysis/upper_arm_static_fea/results/upper_arm_static_fea_von_mises.png`
- 位移图：`<repo>/07_fea_analysis/upper_arm_static_fea/results/upper_arm_static_fea_displacement.png`

## 当前边界

- 这是第一版开源工具链 screening FEA，边界条件采用 x 方向区域选择，还不是基于真实螺钉接触、轴承接触或舵机装配接触的高保真模型。
- STL 到四面体网格会带来离散误差，后续可用 STEP/B-Rep 特征进一步定义孔壁、接触面和载荷面。
- 结果适合用于方案筛选、作品集方法展示和下一轮设计判断，不作为最终生产强度认证。

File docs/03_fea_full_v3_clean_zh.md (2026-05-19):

# SO-101 upper_arm_link full V3 CAE 几何清理与 FEA 报告

## 这一步在做什么

Step 20 针对 full V3 在 7 mm 网格下出现的 `overlapping facets` 问题进行 CAE 几何清理验证。诊断发现，小装配孔和沉孔不是不能做 FEA，而是 7 mm 目标网格相对 M3 通孔、沉孔和夹紧孔过粗。将目标四面体网格尺寸降到 5.0 mm 后，full V3 带完整小孔和沉孔可以成功网格化。

## 工况设定

- official：官方 `Upper_arm_SO101.step`，重新用 5.0 mm 网格划分。
- V3：Gmsh/OpenCASCADE 参数化重建的 full V3 CAE 几何，包含肩部夹紧孔、肘部安装通孔和沉孔。
- 材料：PLA screening，弹性模量 2500 MPa，泊松比 0.35，屈服强度按 50 MPa 做 screening。
- 约束/载荷：沿零件最长方向，shoulder 侧前 12% 固定，elbow 侧后 10% 施加 10.0 N 向下力。

## 核心结果

| 版本 | 几何 | 网格尺寸 mm | 节点数 | 四面体数 | 质量 g | 最大位移 mm | 最大 von Mises MPa | p95 von Mises MPa | 屈服安全系数 |
|---|---|---:|---:|---:|---:|---:|---:|---:|---:|
| official | step_refined_5mm | 5.0 | 3750 | 12410 | 144.07 | 0.024591 | 0.327 | 0.140 | 153.11 |
| full V3 | full_v3_cae_clean_5mm | 5.0 | 3255 | 11048 | 127.49 | 0.071577 | 0.770 | 0.335 | 64.96 |

## 对比结论

- full V3 相对 official 的估算质量变化：-11.51%。
- full V3 相对 official 的最大位移变化：+191.07%。
- full V3 相对 official 的最大 von Mises 应力变化：+135.71%。
- full V3 的 CAE 网格问题已初步解决：关键不是删除小孔，而是对小孔/沉孔区域采用更细的网格。
- 这一步把 Step 18 的“特征抑制版 V3”推进到“完整孔系 full V3 可网格化 FEA”。

## 输出文件

- 清理后的 full V3 STEP：`<repo>/07_fea_analysis/upper_arm_static_fea/results_full_v3_clean/v3_full_cae_clean_5mm.step`
- 指标 JSON：`<repo>/07_fea_analysis/upper_arm_static_fea/results_full_v3_clean/upper_arm_full_v3_clean_fea_metrics.json`
- 指标 CSV：`<repo>/07_fea_analysis/upper_arm_static_fea/results_full_v3_clean/upper_arm_full_v3_clean_fea_metrics.csv`
- official VTK：`<repo>/07_fea_analysis/upper_arm_static_fea/results_full_v3_clean/official_upper_arm_full_v3_clean_fea.vtu`
- full V3 VTK：`<repo>/07_fea_analysis/upper_arm_static_fea/results_full_v3_clean/v3_full_upper_arm_full_v3_clean_fea.vtu`
- 应力图：`<repo>/07_fea_analysis/upper_arm_static_fea/results_full_v3_clean/upper_arm_full_v3_clean_fea_von_mises.png`
- 位移图：`<repo>/07_fea_analysis/upper_arm_static_fea/results_full_v3_clean/upper_arm_full_v3_clean_fea_displacement.png`

## 当前边界

- 当前解决的是 full V3 在 Gmsh 下的体网格可生成问题，还不是最终高保真接触仿真。
- 约束/载荷仍是区域式 screening；后续还应在 full V3 clean mesh 上继续做接口边界工况。
- 更细网格会增加计算量，但这是小孔和沉孔进入 CAE 的必要代价。

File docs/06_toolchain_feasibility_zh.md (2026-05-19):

# Ubuntu 22.04 下 ROS2 / colcon / FreeCAD / CalculiX 可用性说明

## 结论

当前服务器是 Ubuntu 22.04.5，可以继续使用这些工具，但路线要分清：

- ROS2：应使用 **ROS2 Humble**，不要在 22.04 上强行按 `so101-ros-physical-ai` 的 Jazzy/Ubuntu 24.04 路线安装。
- colcon：可以随 ROS2 开发工具安装，也可以用 Python 方式安装；当前服务器还没有。
- FreeCAD：Ubuntu 22.04 apt 源中有 `freecad`，版本候选为 `0.19.2+dfsg1-3ubuntu1`。
- CalculiX：Ubuntu 22.04 apt 源中有 `calculix-ccx`，版本候选为 `2.17-3`。
- Gmsh：系统 apt 源中有 `gmsh`，版本候选为 `4.8.4+ds2-2build1`；同时当前 `text-to-cad` venv 已有 Python `gmsh 4.15.2`。

## 当前服务器实际状态

| 工具 | 当前是否已安装 | Ubuntu 22.04 是否可用 | 备注 |
|---|---|---|---|
| `ros2` | 未安装 | 可用，推荐 ROS2 Humble | 需要添加 ROS2 apt 源后安装。 |
| `colcon` | 未安装 | 可用 | 建议随 ROS2 开发工具安装。 |
| `freecad` / `freecadcmd` | 未安装 | 可用 | apt 源有 0.19.2，适合基础 FreeCAD FEM/STEP 检查；如需新版可考虑 AppImage/conda。 |
| `ccx` | 未安装 | 可用 | apt 源有 `calculix-ccx 2.17-3`。 |
| 系统 `gmsh` | 未安装 | 可用 | apt 源有 4.8.4；当前 Python venv 已有 `gmsh 4.15.2`。 |
| Docker | 命令存在 | 当前不可直接用 | 用户无 `/var/run/docker.sock` 权限。 |

## 推荐安装路线

### 路线 A：先补 CAE 工具，风险最低

优先安装：

```bash
sudo apt update
sudo apt install -y freecad calculix-ccx gmsh
```

作用：

- `freecad/freecadcmd`：用于 FreeCAD FEM、STEP 检查、CAD 转换和自动化脚本。
- `ccx`：用于 CalculiX 线性静力求解，把当前 FEA 从自建 screening 升级到开源求解器流程。
- `gmsh`：用于系统级网格生成；Python venv 的 gmsh 仍可继续保留。

这条线和当前项目最直接相关，因为我们已经有 STEP、Gmsh mesh、VTK/PNG 后处理。

### 路线 B：ROS2 使用 Humble，不使用 Jazzy

Ubuntu 22.04 对应 ROS2 Humble。安装完成后再装 MoveIt 相关包。

推荐思路：

```bash
# 添加 ROS2 apt 源后
sudo apt update
sudo apt install -y ros-humble-desktop python3-colcon-common-extensions python3-rosdep
```

然后：

```bash
source /opt/ros/humble/setup.bash
ros2 --version
colcon --help
```

注意：

- `so101-ros-physical-ai` README 写的是 Ubuntu 24.04 + ROS2 Jazzy。
- 在当前服务器 22.04 上，完整复现该项目需要做 Humble 适配，不能完全照搬 Jazzy 的依赖。
- 短期可以先做 `so101_description`/URDF/mesh 层整合；中期再用 Humble 跑 RViz/MoveIt。

### 路线 C：Jazzy 用容器或 24.04 环境

如果后续一定要严格复现 `so101-ros-physical-ai` 原项目，推荐：

- Ubuntu 24.04 + ROS2 Jazzy 实机/虚拟机；或
- Docker 容器跑 Ubuntu 24.04 + ROS2 Jazzy。

当前问题：

- 服务器已有 Docker 命令，但当前用户没有 Docker daemon 权限。
- 需要管理员把当前用户加入 docker 组，或提供可用容器环境。

## 对当前项目的建议

建议不要一次性安装所有工具。顺序应为：

1. 先安装 `freecad calculix-ccx gmsh`，把 CAE 工具链补起来。
2. 用 CalculiX 重跑 official / full V3 / V4 的静力分析，生成 `.inp`、`.frd/.dat`、VTK/PNG。
3. 再安装 ROS2 Humble + colcon，先跑 `so101_description`/RViz/MoveIt 的基础显示和规划。
4. 等 Docker 或 Ubuntu 24.04 环境可用后，再完整复现 Jazzy 版 `so101-ros-physical-ai`。

## 这一步的工程意义

这一步明确了工具链不是“不能用”，而是要按 Ubuntu 22.04 的生态重新选型：

- ROS2 走 Humble。
- CAE 走 FreeCAD + Gmsh + CalculiX。
- Jazzy/24.04 作为后续容器或新环境目标。

这样项目不会因为版本不匹配卡住，同时仍然能逐步接入成熟开源工具链。

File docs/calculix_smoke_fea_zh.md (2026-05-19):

# SO-101 upper_arm_link CalculiX 求解链 smoke test 报告

## 这一步在做什么

Step 23 使用 Step 20 已经跑通的 official / full V3 clean 5 mm 四面体网格，生成 CalculiX `.inp` 文件，并调用 `ccx` 运行线性静力求解。

这一步的目标不是替代最终高保真 FEA，而是先证明开源 CAE 求解链已经打通：

```text
Gmsh 四面体网格 -> CalculiX .inp -> ccx 求解 -> .dat/.frd 结果文件
```

## 工具链

- CalculiX：`ccx 2.23`
- 输入网格：Step 20 full V3 clean 5 mm `.msh`
- 单元：一阶四面体 `C3D4`
- 材料：PLA screening，E=2500 MPa，nu=0.35
- 载荷：沿零件最长方向，shoulder 侧固定，elbow 侧施加总计 10 N 向下力

## 核心结果

| 版本 | 状态 | 节点 | 四面体 | 固定节点 | 加载节点 | 最大加载位移 mm | 最大 von Mises MPa | 安全系数 |
|---|---|---:|---:|---:|---:|---:|---:|---:|
| official | PASS | 3750 | 12410 | 679 | 569 | 0.024591 | 0.327 | 153.11 |
| v3_full | PASS | 3255 | 11048 | 491 | 213 | 0.071577 | 0.770 | 64.96 |

## 输出文件大小检查

| 版本 | ccx 返回码 | DAT bytes | FRD bytes |
|---|---:|---:|---:|
| official | 0 | 2487588 | 1702805 |
| v3_full | 0 | 2199044 | 1498439 |

## 输出文件

- 指标 CSV：`<repo>/07_fea_analysis/upper_arm_static_fea/results_calculix_smoke/upper_arm_calculix_smoke_metrics.csv`
- 指标 JSON：`<repo>/07_fea_analysis/upper_arm_static_fea/results_calculix_smoke/upper_arm_calculix_smoke_metrics.json`

### official

- INP：`<repo>/07_fea_analysis/upper_arm_static_fea/results_calculix_smoke/official/official_upper_arm_ccx_smoke.inp`
- DAT：`<repo>/07_fea_analysis/upper_arm_static_fea/results_calculix_smoke/official/official_upper_arm_ccx_smoke.dat`
- FRD：`<repo>/07_fea_analysis/upper_arm_static_fea/results_calculix_smoke/official/official_upper_arm_ccx_smoke.frd`
- LOG：`<repo>/07_fea_analysis/upper_arm_static_fea/results_calculix_smoke/official/official_upper_arm_ccx_smoke_ccx.log`

### full V3

- INP：`<repo>/07_fea_analysis/upper_arm_static_fea/results_calculix_smoke/v3_full/v3_full_upper_arm_ccx_smoke.inp`
- DAT：`<repo>/07_fea_analysis/upper_arm_static_fea/results_calculix_smoke/v3_full/v3_full_upper_arm_ccx_smoke.dat`
- FRD：`<repo>/07_fea_analysis/upper_arm_static_fea/results_calculix_smoke/v3_full/v3_full_upper_arm_ccx_smoke.frd`
- LOG：`<repo>/07_fea_analysis/upper_arm_static_fea/results_calculix_smoke/v3_full/v3_full_upper_arm_ccx_smoke_ccx.log`

## 当前结论

- 如果两个 case 都为 `PASS`，说明 CalculiX 求解器链路已经可用于本项目。
- 下一步可以开始把 Python screening solver 的结果与 `ccx` 的位移/应力结果做同口径对比。
- 之后再考虑更复杂的边界条件、孔壁面载荷、螺钉接触、打印方向和材料各向异性。

## 当前边界

- 这是 smoke test，只验证求解链路，不作为最终强度结论。
- 当前仍使用节点集合近似固定和加载区域，没有做真实接触。
- 当前使用 C3D4 一阶四面体，后续可以评估 C3D10 或网格收敛。

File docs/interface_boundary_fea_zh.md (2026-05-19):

# SO-101 upper_arm_link Official / V3 接口边界静力有限元对比

## 这一步在做什么

Step 19 在 Step 18 已经跑通的四面体网格基础上，只升级边界条件：从“固定/加载一大段长度区域”改为“固定/加载靠近 shoulder/elbow 端部接口的窄区域节点”。这样可以更接近机械接口受力，而不改变材料、网格和总载荷。

## 工况设定

- 几何和网格：复用 Step 18 的 official STEP 网格和 V3 可网格化 CAE 变体网格。
- 单位体系：mm、N、MPa。
- 材料：PLA screening，弹性模量 2500 MPa，泊松比 0.35，屈服强度按 50 MPa 做 screening。
- 约束：固定 shoulder 侧端部接口窄带节点。
- 载荷：在 elbow 侧端部接口窄带节点施加合力 10.0 N，方向为 Z 负方向。
- 边界节点选择：从 2.0 mm 端部窄带开始，如果节点太少，自动放宽到最多 10.0 mm。

## 核心结果

| 版本 | 主轴 | 固定节点 | 加载节点 | 固定带宽 mm | 加载带宽 mm | 质量 g | 最大位移 mm | 最大 von Mises MPa | p95 von Mises MPa | 屈服安全系数 |
|---|---|---:|---:|---:|---:|---:|---:|---:|---:|---:|
| official | x | 102 | 27 | 2.0 | 3.0 | 143.18 | 0.033668 | 0.726 | 0.187 | 68.90 |
| V3 | x | 56 | 25 | 2.0 | 4.0 | 129.66 | 0.086954 | 0.636 | 0.381 | 78.60 |

## 对比结论

- V3 相对 official 的估算质量变化：-9.44%。
- V3 相对 official 的最大位移变化：+158.27%。
- V3 相对 official 的最大 von Mises 应力变化：-12.34%。
- 与 Step 18 相比，Step 19 的意义不是追求更好看的数值，而是让边界条件更像真实接口载荷；这会让应力集中更明显，也更适合指导下一版结构加强。

## 输出文件

- 指标 JSON：`<repo>/07_fea_analysis/upper_arm_static_fea/results_interface_boundary/upper_arm_interface_fea_metrics.json`
- 指标 CSV：`<repo>/07_fea_analysis/upper_arm_static_fea/results_interface_boundary/upper_arm_interface_fea_metrics.csv`
- official VTK：`<repo>/07_fea_analysis/upper_arm_static_fea/results_interface_boundary/official_upper_arm_interface_fea.vtu`
- V3 VTK：`<repo>/07_fea_analysis/upper_arm_static_fea/results_interface_boundary/v3_upper_arm_interface_fea.vtu`
- 应力图：`<repo>/07_fea_analysis/upper_arm_static_fea/results_interface_boundary/upper_arm_interface_fea_von_mises.png`
- 位移图：`<repo>/07_fea_analysis/upper_arm_static_fea/results_interface_boundary/upper_arm_interface_fea_displacement.png`

## 当前边界

- 当前仍是端部接口窄带节点选择，还不是从 STEP B-Rep 精确识别孔壁面、螺钉接触面或轴承接触面。
- V3 仍采用 Step 18 跑通的 `no_small_mount_holes` CAE 变体；full V3 的小装配孔和沉孔仍需要继续清理。
- 这一步适合用于“FEA 边界条件升级”和“V4 加强设计依据”，不作为最终生产强度认证。

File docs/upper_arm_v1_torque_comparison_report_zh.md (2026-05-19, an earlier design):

# upper_arm_v1 惯量更新与静载力矩对比报告

## 目的

验证 `upper_arm_v1` 减重后，在 URDF 惯量层面是否会降低 SO-101 的静载关节力矩。

## 方法

- 保留官方 URDF 作为 baseline，不覆盖 `00_source_snapshot/`。
- 使用 Step 8 的 STL 体积对比得到 V1 / 官方 upper arm 的体积比例。
- 将官方 `upper_arm_link` 的质量和惯量张量按同一比例缩放，生成 inertial screening 版 URDF。
- 使用同一批随机关节姿态，对官方版和 V1 inertial 版分别计算静载关节力矩。
- 该方法是工程筛查，不是最终真实惯量标定。

## 质量与惯量更新

- 官方 upper arm STL 体积：117328.19 mm^3
- V1 upper arm STL 体积：93885.71 mm^3
- V1 / 官方体积比例：0.8002
- 官方 URDF `upper_arm_link` 质量：0.103000 kg
- V1 screening 质量：0.082420 kg
- 质量变化：-0.020580 kg (-19.98%)

说明：官方 URDF link 质量和 STL 体积估算质量并不完全一致。因此本步骤采用“URDF 质量按 STL 体积比例缩放”的筛查方式，目的是观察趋势，不作为最终物理参数。

## 0.10 kg Payload 下的 p95 静载力矩对比

| 关节 | 官方 p95 Nm | V1 p95 Nm | 变化 Nm | 变化比例 |
|---|---:|---:|---:|---:|
| shoulder_pan | 0.0000 | 0.0000 | -0.0000 | -1.68% |
| shoulder_lift | 1.1431 | 1.1268 | -0.0163 | -1.43% |
| elbow_flex | 0.7126 | 0.7126 | 0.0000 | 0.00% |
| wrist_flex | 0.2724 | 0.2724 | 0.0000 | 0.00% |
| wrist_roll | 0.0050 | 0.0050 | -0.0000 | -0.00% |

说明：`shoulder_pan` 的静载重力力矩接近 0，因此它的百分比变化没有实际工程意义，主要看绝对值即可。

## 主要结论

- `shoulder_lift` p95 力矩：1.1431 -> 1.1268 Nm，变化 -0.0163 Nm (-1.43%)。
- `elbow_flex` p95 力矩：0.7126 -> 0.7126 Nm，变化 0.0000 Nm (0.00%)。
- 结果符合机械直觉：减轻 upper arm 主要降低 shoulder_lift 负担，对 elbow_flex 的影响很小，因为 upper arm 位于 elbow 上游。

## 当前限制

- 仍未进行真实 CAD 装配孔位校核。
- 仍未进行真实材料、打印方向、局部螺丝柱的 FEA。
- 当前 inertia 是按比例缩放的筛查值，不是从完整 CAD 质量属性直接导出的最终惯量。
- 下一步应把这个结论整理成 before/after 对比表，并决定是否继续优化 lower_arm 或 gripper。

## 生成文件

- `05_improved_design/upper_arm_v1/inertial_compare/so101_upper_arm_v1_inertial_scaled.urdf`
- `05_improved_design/upper_arm_v1/inertial_compare/upper_arm_v1_torque_comparison.csv`
- `05_improved_design/upper_arm_v1/inertial_compare/upper_arm_v1_torque_comparison_plot.png`
- `05_improved_design/upper_arm_v1/inertial_compare/upper_arm_v1_torque_comparison_report_zh.md`
- 静态姿态数量（含 zero pose）：10001

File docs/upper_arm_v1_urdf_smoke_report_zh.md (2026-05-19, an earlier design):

# upper_arm_v1 接回 URDF/PyBullet Smoke Test 报告

## 目的

验证 AI 辅助生成的 `upper_arm_v1` STL 是否可以接回 SO-101 的 URDF/PyBullet 仿真链路。

## 做法

- 复制官方 `Simulation_SO101/assets` 到 `05_improved_design/upper_arm_v1/urdf_smoke/assets`。
- 将 `upper_arm_v1_ai_rebuild.stl` 从毫米单位缩放为米单位，生成 `upper_arm_v1_ai_rebuild_m.stl`。
- 复制官方 URDF，生成 `so101_upper_arm_v1_visual_smoke.urdf`。
- 只替换 `upper_arm_link` 的 3D 打印件 visual mesh，不修改 collision 和 inertial。
- 用同一批随机关节角度比较官方 URDF 和改进 URDF 的末端位置。

## 输入文件

- 官方 URDF：`<repo>/00_source_snapshot/Simulation_SO101/so101_new_calib.urdf`
- 改进 URDF：`<repo>/05_improved_design/upper_arm_v1/urdf_smoke/so101_upper_arm_v1_visual_smoke.urdf`

## Mesh 缩放检查

- V1 原始 STL 包围盒：[150.5, 38.0, 39.299831]
- 缩放后仿真 mesh 包围盒：[0.1505, 0.038, 0.0393] m
- 缩放后 mesh watertight：True

## PyBullet Smoke Test 结果

- 关节名称是否一致：True
- 官方关节数：7
- 改进版关节数：7
- 随机姿态数量（含 zero pose）：2001
- zero pose 末端位置差：0.000000e+00 m
- 最大末端位置差：0.000000e+00 m
- 平均末端位置差：0.000000e+00 m

## 结论

- 改进版 URDF 可以被 PyBullet 加载。
- 关节数量和关节名称保持不变。
- 由于本步骤只替换 visual mesh，不修改 joint、collision、inertial，末端运动学应与官方 baseline 保持一致。
- 这一步证明 V1 CAD/STL 已经能进入机器人仿真链路，不再只是孤立 CAD 文件。

## 当前限制

- 本 smoke test 只替换 visual mesh，尚未替换 collision mesh。
- 尚未把 V1 的质量和惯量写入 URDF。
- 尚未做改进版静载力矩对比；下一步需要基于 V1 粗估质量更新 inertial 后再对比。

## 生成文件

- `05_improved_design/upper_arm_v1/urdf_smoke/so101_upper_arm_v1_visual_smoke.urdf`
- `05_improved_design/upper_arm_v1/urdf_smoke/assets/upper_arm_v1_ai_rebuild_m.stl`
- `05_improved_design/upper_arm_v1/urdf_smoke/upper_arm_v1_urdf_smoke_motion.csv`
- `05_improved_design/upper_arm_v1/urdf_smoke/upper_arm_v1_urdf_smoke_plot.png`
- `05_improved_design/upper_arm_v1/urdf_smoke/upper_arm_v1_urdf_smoke_report_zh.md`

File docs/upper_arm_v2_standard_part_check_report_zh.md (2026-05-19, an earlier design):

# upper_arm_v2 标准件装配与简化干涉检查报告

## 这一步在做什么

Step 14 在 V2 二级孔位校核的基础上，引入简化标准件模型，检查主轴/轴套、M3 螺钉、沉孔和简化舵机连接板是否能与 V2 的孔系匹配。

本步骤不是生产级装配认证，而是作品集阶段的标准件适配性和明显干涉风险筛查。

## 标准件简化假设

- 主关节轴/轴套：半径 4.00 mm，对应约 D8 标准件包络。
- 肘部安装螺钉：M3 简化螺钉，杆部半径 1.50 mm，头部半径 2.60 mm，高度 2.00 mm。
- 肩部夹紧/定位螺钉：M3 简化螺钉，杆部半径 1.50 mm，外侧头部半径 3.00 mm。
- 肘部简化舵机/连接板 footprint：22.0 x 22.0 mm。

## 总体结论

- 装配检查总体状态：`PASS_WITH_WARNINGS`。
- FAIL 项数量：0。
- WARN 项数量：3。

需要注意的 WARN 项：
- `肘部 M3 螺钉通孔径向余量`：0.100 mm。功能上可装入，但 0.10 mm 对 FDM 打印偏紧，建议 V3 放宽到半径 1.70-1.80 mm。
- `肘部 M3 螺钉头沉孔径向余量`：0.100 mm。螺钉头可进入沉孔，但径向余量偏紧。
- `肘部安装孔与 elbow 主孔最小孔间材料`：0.250 mm。这是当前最需要关注的风险：最近的 M3 通孔离 elbow 主孔较近，真实打印和受力下建议 V3 把孔系向近端移动 1-2 mm 或增大局部材料。

## 检查明细

| 检查项 | 要求 | 实测/计算 | 状态 | 说明 |
|---|---|---|---|---|
| 主关节 D8 轴/轴套径向余量 | 孔半径 4.20 mm，应大于标准件半径 4.00 mm | 0.200 mm | PASS | 用于判断 shoulder/elbow 主轴是否能装入。0.20 mm 对 3D 打印属于可用但偏紧的余量。 |
| 肘部 M3 螺钉通孔径向余量 | 孔半径 1.60 mm，应大于 M3 螺钉半径 1.50 mm | 0.100 mm | WARN | 功能上可装入，但 0.10 mm 对 FDM 打印偏紧，建议 V3 放宽到半径 1.70-1.80 mm。 |
| 肘部 M3 螺钉头沉孔径向余量 | 沉孔半径 2.70 mm，应大于头部半径 2.60 mm | 0.100 mm | WARN | 螺钉头可进入沉孔，但径向余量偏紧。 |
| 肘部 M3 螺钉头沉孔深度余量 | 沉孔深度 2.20 mm，应大于头部高度 2.00 mm | 0.200 mm | PASS | 沉孔深度可容纳简化螺钉头。 |
| 肘部安装孔到 pad 边缘最小材料 | 建议 >= 2.0 mm | 通孔边缘 7.450 mm，沉孔边缘 6.350 mm | PASS | 边缘余量充足。 |
| 肘部 2x2 孔间最小材料 | 建议通孔/沉孔之间保留 >= 2.0 mm | 通孔间 6.700 mm，沉孔间 4.500 mm | PASS | 2x2 孔系自身材料余量可接受。 |
| 肘部安装孔与 elbow 主孔最小孔间材料 | 建议 >= 0.8 mm | 0.250 mm | WARN | 这是当前最需要关注的风险：最近的 M3 通孔离 elbow 主孔较近，真实打印和受力下建议 V3 把孔系向近端移动 1-2 mm 或增大局部材料。 |
| 肩部 M3 夹紧/定位孔径向余量 | 孔半径 2.00 mm，应大于 M3 螺钉半径 1.50 mm | 0.500 mm | PASS | 肩部侧向孔给 M3 螺钉留有较宽松余量。 |
| 肩部夹紧孔到 pad 边缘最小材料 | 建议 >= 2.0 mm | 2.500 mm | PASS | 边缘材料余量可接受，但已接近小型打印件下限。 |
| 肩部夹紧孔与 shoulder 主孔最小孔间材料 | 建议 >= 2.0 mm | 7.000 mm | PASS | 肩部夹紧孔与主孔之间有较充足材料。 |
| 简化舵机/连接板 footprint 是否落在 elbow pad 内 | 参考板投影应在 pad 内 | 最小边缘余量 3.000 mm | PASS | 用于检查简化 mating plate 不会明显悬空。 |

## 工程解释

- V2 的主轴、肘部 M3 螺钉、肩部夹紧螺钉在简化尺寸下都能装入对应孔系。
- 但肘部 M3 通孔半径 1.60 mm 对 M3 螺钉的径向余量只有 0.10 mm，真实 FDM/树脂打印时偏紧。
- 最近的肘部 M3 安装孔与 elbow 主孔之间理论材料余量约 0.25 mm，这是当前主要风险点。
- 因此 Step 14 的结论不是“生产级完全通过”，而是“标准件可装入，但 V3 应优化肘部孔系余量”。

## V3 改进建议

- 将肘部 2x2 安装孔中心整体向近端移动 1-2 mm，增大其与 elbow 主孔之间的材料余量。
- 将肘部 M3 通孔半径从 1.60 mm 放宽到 1.70-1.80 mm，提升打印后装配成功率。
- 将 M3 螺钉头沉孔半径从 2.70 mm 放宽到 2.90-3.00 mm，给实际螺钉头和打印误差留余量。
- 在肘部主孔和最近 M3 孔之间增加局部 boss 或加厚 pad，避免薄弱材料桥。

## 输出文件

- 简化标准件装配 STEP：`<repo>/05_improved_design/upper_arm_v2/assembly_check/upper_arm_v2_simplified_standard_parts_assembly.step`
- 简化标准件装配 STL：`<repo>/05_improved_design/upper_arm_v2/assembly_check/upper_arm_v2_simplified_standard_parts_assembly.stl`
- 结构化结果 JSON：`<repo>/05_improved_design/upper_arm_v2/assembly_check/upper_arm_v2_standard_part_check.json`
- 检查明细 CSV：`<repo>/05_improved_design/upper_arm_v2/assembly_check/upper_arm_v2_standard_part_checks.csv`

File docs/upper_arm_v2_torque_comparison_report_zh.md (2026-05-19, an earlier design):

# upper_arm_v2 惯量更新与静载力矩对比报告

## 这一步在做什么

将 `upper_arm_v2` 的体积变化转化为 URDF inertial screening 参数，并与官方 SO-101 baseline 做静载关节力矩对比。

## 方法

- 保留官方 URDF 作为 baseline，不覆盖 `00_source_snapshot/`。
- 使用 V2 STL 与官方 upper arm STL 的体积比例，按比例缩放官方 `upper_arm_link` 的质量和惯量张量。
- 生成 `so101_upper_arm_v2_inertial_scaled.urdf`。
- 使用同一批随机关节姿态，对官方版和 V2 inertial 版计算静载关节力矩。
- 该方法是工程筛查，不是最终真实惯量标定。

## 质量与惯量更新

- 官方 upper arm STL 体积：117328.19 mm^3
- V1 upper arm STL 体积：93885.71 mm^3
- V2 upper arm STL 体积：98626.10 mm^3
- V1 / 官方体积比例：0.8002
- V2 / 官方体积比例：0.8406
- V2 / V1 体积比例：1.0505
- 官方 URDF `upper_arm_link` 质量：0.103000 kg
- V2 screening 质量：0.086582 kg
- V2 相对官方质量变化：-0.016418 kg (-15.94%)

说明：官方 URDF link 质量和 STL 体积估算质量并不完全一致。因此本步骤采用“URDF 质量按 STL 体积比例缩放”的筛查方式，目的是观察趋势，不作为最终物理参数。

## 0.10 kg Payload 下的 p95 静载力矩对比

| 关节 | 官方 p95 Nm | V2 p95 Nm | 变化 Nm | 变化比例 |
|---|---:|---:|---:|---:|
| shoulder_pan | 0.0000 | 0.0000 | -0.0000 | -1.17% |
| shoulder_lift | 1.1440 | 1.1303 | -0.0137 | -1.20% |
| elbow_flex | 0.7142 | 0.7142 | 0.0000 | 0.00% |
| wrist_flex | 0.2724 | 0.2724 | 0.0000 | 0.00% |
| wrist_roll | 0.0050 | 0.0050 | 0.0000 | 0.00% |

## Official / V1 / V2 三版本对比

| 关节 | 官方 p95 Nm | V1 p95 Nm | V2 p95 Nm | V2 相对 V1 变化 Nm |
|---|---:|---:|---:|---:|
| shoulder_pan | 0.0000 | 0.0000 | 0.0000 | 0.0000 |
| shoulder_lift | 1.1440 | 1.1268 | 1.1303 | 0.0035 |
| elbow_flex | 0.7142 | 0.7142 | 0.7142 | -0.0000 |
| wrist_flex | 0.2724 | 0.2724 | 0.2724 | -0.0000 |
| wrist_roll | 0.0050 | 0.0050 | 0.0050 | -0.0000 |

## 主要结论

- `shoulder_lift` p95 力矩：1.1440 -> 1.1303 Nm，变化 -0.0137 Nm (-1.20%)。
- `elbow_flex` p95 力矩：0.7142 -> 0.7142 Nm，变化 0.0000 Nm (0.00%)。
- V2 比 V1 略重，因为补充了装配孔、沉孔和局部加强 pad；它的意义不是追求最轻，而是在保持明显减重的同时提升装配表达能力。
- 结果仍符合机械直觉：upper arm 的质量变化主要影响 `shoulder_lift`，对下游 `elbow_flex` 和 `wrist_flex` 影响很小。

## 当前限制

- 当前 inertia 是按体积比例缩放的筛查值，不是从 CAD 质量属性直接导出的最终惯量。
- Official / V1 / V2 三版本对比使用同一批随机关节姿态重新计算，避免不同随机采样导致的 p95 细微偏差。
- 尚未替换 collision mesh，也尚未引入舵机、轴承、螺丝等标准件做完整装配干涉检查。
- 下一步建议整理 official/V1/V2 总对比报告，或者继续做标准件装配与干涉检查。

## 生成文件

- `05_improved_design/upper_arm_v2/inertial_compare/so101_upper_arm_v2_inertial_scaled.urdf`
- `05_improved_design/upper_arm_v2/inertial_compare/upper_arm_v2_torque_comparison.csv`
- `05_improved_design/upper_arm_v2/inertial_compare/upper_arm_v2_torque_comparison_plot.png`
- `05_improved_design/upper_arm_v2/inertial_compare/upper_arm_v2_torque_comparison_report_zh.md`
- 静态姿态数量（含 zero pose）：10001

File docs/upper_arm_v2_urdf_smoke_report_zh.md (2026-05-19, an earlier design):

# upper_arm_v2 接回 URDF/PyBullet Smoke Test 报告

## 这一步在做什么

验证 `upper_arm_v2` 的 STL 是否可以接回 SO-101 的 URDF/PyBullet 仿真链路，并确认它不会破坏原机器人的关节链和末端运动学。

## 做法

- 复制官方 `Simulation_SO101/assets` 到 V2 的 `urdf_smoke/assets`。
- 将 `upper_arm_v2_ai_rebuild.stl` 从毫米单位缩放为米单位，生成 `upper_arm_v2_ai_rebuild_m.stl`。
- 复制官方 URDF，生成 `so101_upper_arm_v2_visual_smoke.urdf`。
- 只替换 `upper_arm_link` 的 visual mesh，不修改 collision、joint 和 inertial。
- 使用同一批随机关节角度比较官方 URDF 和 V2 visual URDF 的末端位置。

## 输入文件

- 官方 URDF：`<repo>/00_source_snapshot/Simulation_SO101/so101_new_calib.urdf`
- V2 visual smoke URDF：`<repo>/05_improved_design/upper_arm_v2/urdf_smoke/so101_upper_arm_v2_visual_smoke.urdf`

## Mesh 缩放检查

- V2 原始 STL 包围盒：[150.5, 36.0, 39.299236]
- 缩放后仿真 mesh 包围盒：[0.1505, 0.036, 0.039299] m
- 缩放后 mesh watertight：True

## PyBullet Smoke Test 结果

- 关节名称是否一致：True
- 官方关节数：7
- V2 关节数：7
- 随机姿态数量（含 zero pose）：2001
- zero pose 末端位置差：0.000000e+00 m
- 最大末端位置差：0.000000e+00 m
- 平均末端位置差：0.000000e+00 m

## 结论

- V2 visual URDF 可以被 PyBullet 加载。
- 关节数量和关节名称保持不变。
- 由于本步骤只替换 visual mesh，不修改 joint、collision、inertial，末端运动学与官方 baseline 保持一致。
- 这说明 V2 不只是一个独立 CAD 文件，已经重新进入 SO-101 的仿真链路。

## 当前限制

- 本 smoke test 只替换 visual mesh，尚未替换 collision mesh。
- 尚未把 V2 的质量和惯量写入 URDF。
- 需要下一步基于 V2 体积比例更新 inertial，并重新做静载力矩对比。

## 生成文件

- `05_improved_design/upper_arm_v2/urdf_smoke/so101_upper_arm_v2_visual_smoke.urdf`
- `05_improved_design/upper_arm_v2/urdf_smoke/assets/upper_arm_v2_ai_rebuild_m.stl`
- `05_improved_design/upper_arm_v2/urdf_smoke/upper_arm_v2_urdf_smoke_motion.csv`
- `05_improved_design/upper_arm_v2/urdf_smoke/upper_arm_v2_urdf_smoke_plot.png`
- `05_improved_design/upper_arm_v2/urdf_smoke/upper_arm_v2_urdf_smoke_report_zh.md`

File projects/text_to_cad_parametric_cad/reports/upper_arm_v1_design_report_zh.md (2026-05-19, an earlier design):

# upper_arm_link V1 AI 辅助 CAD 重建设计报告

## 当前步骤

Step 8：AI 辅助 `upper_arm_link` 参数化 CAD 重建。

## 这一步做了什么

- 在 `05_improved_design/upper_arm_v1/` 中建立第一版改进件目录。
- 编写 `upper_arm_v1_cad.py`，用 build123d 参数化生成 `upper_arm_link` 第一版重建模型。
- 使用服务器 `<text-to-cad-cad-env>` 中的 CAD 环境导出 STEP/STL。
- 编写 `validate_upper_arm_v1.py`，对官方 STL 和改进 STL 做基础几何对比。
- 生成可编辑源文件、STEP、STL、参数 JSON 和中文验证报告。

## 为什么先做 upper_arm_link

前面 Step 6 和 Step 7 已经得到工程依据：

- 100g 末端负载下，`shoulder_lift` 是主要静载力矩瓶颈。
- `upper_arm_link` 是 shoulder 到 elbow 的主承力结构件。
- 简化结构筛查中，`upper_arm_link` 的结构改进优先级最高。

因此第一轮不重做整台机械臂，而是先对 `upper_arm_link` 做局部参数化重建，风险更可控，也更容易和官方 baseline 对比。

## 设计约束

- 保留 shoulder_lift 到 elbow_flex 的设计跨度：116.0 mm。
- 不修改官方 `00_source_snapshot/`。
- 不改变官方 URDF 的 joint 名称、joint axis 和运动链。
- 不直接声称 V1 已经可以装机打印；它是第一版可编辑 CAD 概念件。

## V1 结构特征

- 上下双 rail：形成主要抗弯路径。
- 中央 web：形成盒式/桁架式受力结构。
- 轻量化孔：降低中部材料用量。
- 竖向 ribs：提高弱轴刚度。
- 顶部线槽：体现线束管理能力。
- 两端 boss：保留 shoulder/elbow 关节接口的参数化位置。

## 导出结果

- `upper_arm_v1_cad.py`：参数化 CAD 源文件。
- `upper_arm_v1_ai_rebuild.step`：STEP CAD 文件。
- `upper_arm_v1_ai_rebuild.stl`：STL mesh 文件。
- `upper_arm_v1_parameters.json`：参数记录。
- `upper_arm_v1_validation_zh.md`：几何验证报告。

## 基础几何对比

| 模型 | watertight | 包围盒尺寸 xyz | 体积 | PLA 估算质量 |
|---|---|---:|---:|---:|
| 官方 upper arm | True | 142.15, 24.50, 67.30 mm | 117328.19 mm^3 | 145.49 g |
| 改进版 V1 | True | 150.50, 38.00, 39.30 mm | 93885.71 mm^3 | 116.42 g |

## 当前结论

- V1 已经成功导出 STEP/STL。
- V1 STL 是 watertight mesh。
- 按 PLA 密度粗估，V1 相比官方 upper arm 体积/质量约下降 20.0%。
- V1 的 z 向高度更低，y 向宽度更大，说明它把结构从高窄形态改成更宽的盒式/桁架式形态。

## 当前限制

- V1 还没有和官方 URDF 完成 mesh 替换。
- V1 还没有做 PyBullet 加载验证。
- V1 还没有做与官方装配孔位的一一精确匹配。
- 当前质量估算基于 STL 体积和 PLA 密度，是粗略比较，不等于真实打印质量。

## 下一步

Step 9：将 `upper_arm_v1` 接回 SO-101 URDF/PyBullet 做 smoke test。

具体要做：

- 复制官方 URDF，建立改进版 URDF，不修改官方 baseline。
- 把 `upper_arm_link` 的 visual mesh 指向 `upper_arm_v1_ai_rebuild.stl`。
- 先只做 visual 替换，不立刻改 collision/inertial。
- 用 PyBullet 检查 URDF 是否能加载、关节是否正常、随机运动是否正常。
- 如果加载成功，再做质量/inertial 替换和力矩对比。

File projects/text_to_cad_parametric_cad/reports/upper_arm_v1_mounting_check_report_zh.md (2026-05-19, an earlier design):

# upper_arm_v1 CAD 装配接口与孔位校核报告

## 这一步在做什么

读取官方 `Upper_arm_SO101.step` 和 AI 重建 `upper_arm_v1_ai_rebuild.step` 的真实 CAD B-Rep 几何，抽取圆柱面特征，检查 V1 的主安装孔、关节轴线、外凸台和 shoulder-to-elbow 中心距是否按设计生成。

这不是只看 STL 外观，而是直接从 STEP 几何里读取圆柱孔/轴/凸台特征。

## 输入文件

- 官方 STEP：`<repo>/00_source_snapshot/STEP_SO101/Upper_arm_SO101.step`
- V1 STEP：`<repo>/05_improved_design/upper_arm_v1/upper_arm_v1_ai_rebuild.step`
- V1 参数：`<repo>/05_improved_design/upper_arm_v1/upper_arm_v1_parameters.json`

## 方法

- 使用 OpenCascade/OCP 读取 STEP。
- 遍历所有 CAD face，筛选圆柱面。
- 将圆柱轴线按 X/Y/Z 分类，主装配孔要求沿 Y 轴。
- V1 一级接口校核公差：半径 ±0.08 mm，位置 ±0.20 mm，轴线误差 <= 2.0 deg。

## STEP 圆柱特征统计

| 模型 | 原始圆柱面数 | 去重后圆柱特征数 | X 轴 | Y 轴 | Z 轴 | 斜轴 |
|---|---:|---:|---:|---:|---:|---:|
| official_upper_arm_step | 86 | 83 | 26 | 8 | 35 | 14 |
| upper_arm_v1_step | 10 | 7 | 0 | 7 | 0 | 0 |

## V1 主接口校核结果

| 检查项 | 设计要求 | 实测/检测结果 | 结论 | 作用 |
|---|---|---|---|---|
| 肩部主孔半径 | 4.200 mm | r=4.200, loc=(0.000, 18.000, -0.000), axis=(-0.000, 1.000, -0.000) | 通过 | 用于保持 shoulder_lift 轴线接口。 |
| 肘部主孔半径 | 4.200 mm | r=4.200, loc=(116.000, 18.000, -0.000), axis=(-0.000, 1.000, -0.000) | 通过 | 用于保持 elbow_flex 轴线接口。 |
| 肩部到肘部主孔中心距 | 116.000 mm | 116.000 | 通过 | 这是 V1 与 URDF 关节距离一致性的核心指标。 |
| 主孔轴线方向 | 沿 Y 轴，误差 <= 2.0 deg | shoulder=0.000 deg, elbow=0.000 deg | 通过 | 孔轴线必须与舵机/转轴方向一致，否则无法装配或会产生偏磨。 |
| 肩部外凸台半径 | 18.000 mm | r=18.000, loc=(0.000, 17.000, -0.000), axis=(-0.000, 1.000, -0.000) | 通过 | 外凸台用于承载肩部连接区域。 |
| 肘部外凸台半径 | 16.500 mm | r=16.500, loc=(116.000, 17.000, -0.000), axis=(-0.000, 1.000, -0.000) | 通过 | 外凸台用于承载肘部连接区域。 |

## V1 检测到的主要 Y 轴接口特征

| 半径 mm | 圆柱轴 | 轴线误差 deg | 圆柱位置 x,y,z mm | 重复面数 |
|---:|---|---:|---:|---:|
| 18.000 | Y | 0.000 | 0.000, 17.000, -0.000 | 2 |
| 16.500 | Y | 0.000 | 116.000, 17.000, -0.000 | 1 |
| 6.000 | Y | 0.000 | 38.000, 3.400, -0.000 | 1 |
| 6.000 | Y | 0.000 | 58.000, 3.400, -0.000 | 2 |
| 6.000 | Y | 0.000 | 78.000, 3.400, -0.000 | 1 |
| 4.200 | Y | 0.000 | 0.000, 18.000, -0.000 | 2 |
| 4.200 | Y | 0.000 | 116.000, 18.000, -0.000 | 1 |

## 官方 STEP 的 Y 轴圆柱参考特征

官方件的圆柱特征明显更复杂，包含主轴孔、螺丝孔、圆角/倒角衍生圆柱面等。下面列出半径较大的 Y 轴圆柱特征作为后续 V2 复刻装配孔位的参考。

| 半径 mm | 圆柱轴 | 轴线误差 deg | 圆柱位置 x,y,z mm | 重复面数 |
|---:|---|---:|---:|---:|
| 8.000 | Y | 0.000 | -19.085, -0.000, -0.000 | 1 |
| 8.000 | Y | 0.000 | 23.000, 24.000, 0.000 | 1 |
| 2.000 | Y | 0.000 | -63.085, 0.000, -23.000 | 1 |
| 2.000 | Y | 0.000 | -63.085, 12.000, 23.000 | 1 |

## 结论

- V1 一级接口自检：`PASS`。
- V1 检测到 shoulder 主孔和 elbow 主孔，中心距为 `116.000` mm，设计目标为 `116.000` mm。
- V1 的主孔轴线沿 Y 轴，满足与 URDF 关节轴线一致的一级要求。
- 但 V1 目前没有完整复刻官方 upper arm 的全部螺丝孔、定位台阶和装配 mating 特征，所以不能直接宣称已经是最终可装机零件。
- 这一步的工程结论应表述为：`主关节接口几何通过一级校核；完整 CAD 装配孔位仍需 V2 继续补充官方孔系与装配基准`。

## 这一步的意义

- 把“AI 生成了一个好看的模型”推进到“AI 生成件接受 CAD 特征级校核”。
- 证明 V1 至少保住了机械臂运动链最关键的两个接口：shoulder_lift 与 elbow_flex 的轴线和中心距。
- 也明确暴露了下一步真实工程难点：需要从官方 STEP 或舵机规格中提取完整孔系，再做装配干涉和螺栓可达性检查。

## 下一步

Step 11 建议做 `upper_arm_v2`：在 V1 参数化模型基础上补充官方孔系/舵机安装孔/定位台阶，然后重新运行本脚本做二级装配孔位校核。

## 输出文件

- 圆柱特征 CSV：`<repo>/05_improved_design/upper_arm_v1/mounting_check/upper_arm_v1_mounting_cylinders.csv`
- 结构化校核 JSON：`<repo>/05_improved_design/upper_arm_v1/mounting_check/upper_arm_v1_mounting_check.json`
- 中文报告：`<repo>/05_improved_design/upper_arm_v1/mounting_check/upper_arm_v1_mounting_check_report_zh.md`

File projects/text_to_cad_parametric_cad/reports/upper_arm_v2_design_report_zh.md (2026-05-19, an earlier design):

# upper_arm_link V2 AI 辅助结构迭代设计报告

## 这一步在做什么

Step 11 在 `upper_arm_v1` 的基础上生成 `upper_arm_v2`。V1 已经证明主关节孔、中心距和 URDF 仿真链路可行，但它的装配特征还比较少。V2 的目标是把模型从“概念轻量化结构”推进到“包含明确装配孔系的结构件”。

## 为什么做这一步

V1 的主要价值是建立了参数化 CAD、STEP/STL 导出、URDF smoke test 和初步力矩收益验证。但 V1 的问题也很明确：

- 只有主轴孔、凸台和轻量化孔。
- 没有明确的舵机安装孔系。
- 没有肩部侧向夹紧/定位孔。
- 不能充分体现机械结构设计中最重要的装配接口思维。

因此 V2 的重点不是继续追求更轻，而是补充可解释、可校核的孔位和安装结构。

## V2 相比 V1 改了什么

1. 保留 V1 的 shoulder-to-elbow 主关节中心距：116.000 mm。
2. 保留 shoulder 与 elbow 主孔半径：4.200 mm。
3. 保留 shoulder 与 elbow 外凸台结构。
4. 在肘部 pad 上增加 2x2 舵机/连接件安装孔：
   - 通孔半径：1.600 mm。
   - 孔距：9.900 mm x 9.900 mm。
   - 中心位置：x=105.000 mm。
   - 增加 2.700 mm 半径的沉孔/让位特征。
5. 在肩部 pad 上增加两个侧向夹紧/定位孔：
   - 通孔半径：2.000 mm。
   - 位置：x=-8.000 mm，z=±10.500 mm。
6. 调整 web 与 rib：
   - web 厚度从 2.8 mm 增加到 3.0 mm。
   - web 高度从 26.0 mm 增加到 28.0 mm。
   - rib 厚度从 5.0 mm 增加到 5.5 mm。
7. 轻量化孔半径从 6.0 mm 调整为 5.4 mm，为新增装配孔和局部加强留出材料。

## 设计取舍

V2 相比 V1 体积增加约 4740.39 mm^3，PLA 粗估质量从 116.42 g 增加到 122.30 g，增幅约 5.05%。这不是设计退步，而是为了补充装配孔位、沉孔和局部加强 pad。

对机械设计项目来说，V2 的逻辑是：

- V1：先证明能轻量化和接回仿真。
- V2：补足装配接口，让结构更接近真实工程零件。

也就是说，V2 是用少量质量换取装配表达能力和接口可靠性。

## 中间遇到的问题和解决方式

第一次生成 V2 后，新增的舵机孔和肩部定位孔能被 STEP 检测到，但肩部主孔没有通过校核。

原因：

- 肩部加强 pad 与 boss 融合后，把原本的主轴孔特征覆盖/填充了。
- 这说明加强结构可能破坏关键装配接口。

解决方式：

- 在所有 pad、rib、boss 融合完成后，最后统一重新切削 shoulder 和 elbow 主轴孔。
- 这样可以保证任何加强结构都不能覆盖主孔。

这个问题本身很适合写进作品集，因为它体现了真实 CAD 迭代中的工程检查：不是生成完模型就结束，而是通过孔位校核发现问题，再修复建模顺序。

## 验证结果

几何验证：

- 官方 upper arm STL 体积：117328.19 mm^3，PLA 粗估质量 145.49 g。
- V1 体积：93885.71 mm^3，PLA 粗估质量 116.42 g。
- V2 体积：98626.10 mm^3，PLA 粗估质量 122.30 g。
- V2 相对官方仍减少约 15.94% 体积。
- V2 相对 V1 增加约 5.05% 体积。
- V2 STL 为 watertight。

孔位校核：

- V2 主关节接口复核：PASS。
- V2 新增装配孔系校核：PASS。
- V2 二级装配孔位校核总体：PASS。
- V2 STEP 去重后圆柱特征数从 V1 的 7 个增加到 21 个。

## 当前边界

V2 仍然不是生产级最终装配认证，原因是：

- 官方 STEP 和 V2 的完整装配基准还没有做严格 mating transform。
- 还没有引入舵机、螺丝、轴承等标准件模型做真实干涉检查。
- 还没有进行真实 3D 打印、公差补偿和装机测试。

因此当前准确表述是：V2 已完成 CAD 特征级二级孔位校核，但仍需要标准件装配和干涉检查。

## 下一步

Step 12 建议将 `upper_arm_v2` 接回 URDF/PyBullet，重复 V1 的 visual smoke test，并重新计算 V2 的质量更新与静载力矩影响，形成 official、V1、V2 的 before-after 对比表。

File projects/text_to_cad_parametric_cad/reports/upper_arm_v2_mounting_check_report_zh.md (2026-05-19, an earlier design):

# upper_arm_v2 CAD 二级装配孔位校核报告

## 这一步在做什么

在 V1 主关节接口校核通过的基础上，检查 V2 新增的装配孔系是否真实写入 STEP：包括肘部 2x2 舵机安装孔和肩部侧向夹紧/定位孔。

## 输入文件

- 官方 STEP：`<repo>/00_source_snapshot/STEP_SO101/Upper_arm_SO101.step`
- V1 STEP：`<repo>/05_improved_design/upper_arm_v1/upper_arm_v1_ai_rebuild.step`
- V2 STEP：`<repo>/05_improved_design/upper_arm_v2/upper_arm_v2_ai_rebuild.step`
- V2 参数：`<repo>/05_improved_design/upper_arm_v2/upper_arm_v2_parameters.json`

## 圆柱特征统计

| 模型 | 去重后圆柱特征数 | X 轴 | Y 轴 | Z 轴 | 斜轴 |
|---|---:|---:|---:|---:|---:|
| official_upper_arm_step | 83 | 26 | 8 | 35 | 14 |
| upper_arm_v1_step | 7 | 0 | 7 | 0 | 0 |
| upper_arm_v2_step | 21 | 0 | 9 | 12 | 0 |

## 主关节接口复核

| 检查项 | 设计要求 | 实测/检测结果 | 结论 | 作用 |
|---|---|---|---|---|
| 肩部主孔半径 | 4.200 mm | r=4.200, loc=(0.000, 22.000, -0.000), axis=(-0.000, 1.000, -0.000) | 通过 | 保持 shoulder_lift 轴线接口。 |
| 肘部主孔半径 | 4.200 mm | r=4.200, loc=(116.000, 18.000, -0.000), axis=(-0.000, 1.000, -0.000) | 通过 | 保持 elbow_flex 轴线接口。 |
| 肩部到肘部主孔中心距 | 116.000 mm | 116.000 | 通过 | 保证 V2 不破坏原运动链长度。 |
| 主孔轴线方向 | 沿 Y 轴，误差 <= 2.0 deg | shoulder=0.000 deg, elbow=0.000 deg | 通过 | 主孔轴线必须与转轴方向一致。 |
| 肩部外凸台半径 | 18.000 mm | r=18.000, loc=(0.000, 17.000, -0.000), axis=(-0.000, 1.000, -0.000) | 通过 | 保留肩部承载区域。 |
| 肘部外凸台半径 | 16.500 mm | r=16.500, loc=(116.000, 17.000, -0.000), axis=(-0.000, 1.000, -0.000) | 通过 | 保留肘部承载区域。 |

## V2 新增装配孔系校核

| 检查项 | 设计要求 | 实测/检测结果 | 结论 | 作用 |
|---|---|---|---|---|
| 肘部 2x2 舵机安装孔 1 | Z 轴通孔 r=1.600 mm, x=100.050, y=-4.950 | r=1.600, loc=(100.050, -4.950, -21.500), axis=(0.000, 0.000, 1.000) | 通过 | 对应 V2 新增的舵机/连接件安装孔。 |
| 肘部 2x2 舵机安装孔 2 | Z 轴通孔 r=1.600 mm, x=100.050, y=4.950 | r=1.600, loc=(100.050, 4.950, -21.500), axis=(0.000, 0.000, 1.000) | 通过 | 对应 V2 新增的舵机/连接件安装孔。 |
| 肘部 2x2 舵机安装孔 3 | Z 轴通孔 r=1.600 mm, x=109.950, y=-4.950 | r=1.600, loc=(109.950, -4.950, -21.500), axis=(0.000, 0.000, 1.000) | 通过 | 对应 V2 新增的舵机/连接件安装孔。 |
| 肘部 2x2 舵机安装孔 4 | Z 轴通孔 r=1.600 mm, x=109.950, y=4.950 | r=1.600, loc=(109.950, 4.950, -21.500), axis=(0.000, 0.000, 1.000) | 通过 | 对应 V2 新增的舵机/连接件安装孔。 |
| 肩部侧向夹紧/定位孔 1 | Y 轴通孔 r=2.000 mm, x=-8.000, z=-10.500 | r=2.000, loc=(-8.000, 22.000, -10.500), axis=(-0.000, 1.000, -0.000) | 通过 | 对应 V2 新增的肩部定位或夹紧接口。 |
| 肩部侧向夹紧/定位孔 2 | Y 轴通孔 r=2.000 mm, x=-8.000, z=10.500 | r=2.000, loc=(-8.000, 22.000, 10.500), axis=(-0.000, 1.000, -0.000) | 通过 | 对应 V2 新增的肩部定位或夹紧接口。 |

## V2 检测到的装配相关圆柱特征

| 半径 mm | 圆柱轴 | 轴线误差 deg | 圆柱位置 x,y,z mm | 重复面数 |
|---:|---|---:|---:|---:|
| 18.000 | Y | 0.000 | 0.000, 17.000, -0.000 | 2 |
| 16.500 | Y | 0.000 | 116.000, 17.000, -0.000 | 1 |
| 5.400 | Y | 0.000 | 38.000, 3.500, -0.000 | 1 |
| 5.400 | Y | 0.000 | 58.000, 3.500, -0.000 | 2 |
| 5.400 | Y | 0.000 | 78.000, 3.500, -0.000 | 1 |
| 4.200 | Y | 0.000 | 0.000, 22.000, -0.000 | 1 |
| 4.200 | Y | 0.000 | 116.000, 18.000, -0.000 | 1 |
| 2.000 | Y | 0.000 | -8.000, 22.000, -10.500 | 1 |
| 2.000 | Y | 0.000 | -8.000, 22.000, 10.500 | 1 |
| 2.700 | Z | 90.000 | 100.050, -4.950, -17.550 | 1 |
| 2.700 | Z | 90.000 | 100.050, -4.950, 15.250 | 1 |
| 2.700 | Z | 90.000 | 100.050, 4.950, -17.550 | 1 |
| 2.700 | Z | 90.000 | 100.050, 4.950, 15.250 | 1 |
| 2.700 | Z | 90.000 | 109.950, -4.950, -17.550 | 1 |
| 2.700 | Z | 90.000 | 109.950, -4.950, 15.250 | 1 |
| 2.700 | Z | 90.000 | 109.950, 4.950, -17.550 | 1 |
| 2.700 | Z | 90.000 | 109.950, 4.950, 15.250 | 1 |
| 1.600 | Z | 90.000 | 100.050, -4.950, -21.500 | 2 |
| 1.600 | Z | 90.000 | 100.050, 4.950, -21.500 | 2 |
| 1.600 | Z | 90.000 | 109.950, -4.950, -21.500 | 1 |
| 1.600 | Z | 90.000 | 109.950, 4.950, -21.500 | 1 |

## 官方 STEP 中可作为参考的孔/台阶特征

下表不是一一坐标对齐结论，而是说明官方件确实存在大量 Z 轴螺丝孔、Y 轴定位/主孔等装配特征。V2 当前做的是结构化补齐，而不是完全复制官方所有曲面与倒角。

| 半径 mm | 圆柱轴 | 轴线误差 deg | 圆柱位置 x,y,z mm | 重复面数 |
|---:|---|---:|---:|---:|
| 8.000 | Y | 0.000 | -19.085, -0.000, -0.000 | 1 |
| 8.000 | Y | 0.000 | 23.000, 24.000, 0.000 | 1 |
| 2.000 | Y | 0.000 | -63.085, 0.000, -23.000 | 1 |
| 2.000 | Y | 0.000 | -63.085, 12.000, 23.000 | 1 |
| 3.000 | Z | 90.000 | 65.085, 12.000, -19.700 | 2 |
| 3.000 | Z | 90.000 | 65.085, 12.000, 19.700 | 2 |
| 2.700 | Z | 90.000 | 60.135, 7.050, -36.000 | 1 |
| 2.700 | Z | 90.000 | 60.135, 7.050, 36.000 | 1 |
| 2.700 | Z | 90.000 | 60.135, 16.950, -36.000 | 1 |
| 2.700 | Z | 90.000 | 60.135, 16.950, 36.000 | 1 |
| 2.700 | Z | 90.000 | 70.035, 7.050, -36.000 | 1 |
| 2.700 | Z | 90.000 | 70.035, 7.050, 36.000 | 1 |
| 2.700 | Z | 90.000 | 70.035, 16.950, -36.000 | 1 |
| 2.700 | Z | 90.000 | 70.035, 16.950, 36.000 | 1 |
| 2.000 | Z | 90.000 | -63.085, 2.000, 25.000 | 1 |
| 2.000 | Z | 90.000 | -63.085, 22.500, 25.000 | 2 |
| 2.000 | Z | 90.000 | -57.735, 7.200, -10.107 | 1 |
| 2.000 | Z | 90.000 | -57.650, 11.000, 9.107 | 1 |
| 2.000 | Z | 90.000 | -37.235, 7.200, -10.107 | 1 |
| 2.000 | Z | 90.000 | -37.150, 11.000, 9.107 | 1 |
| 1.600 | Z | 90.000 | 65.085, 12.000, 31.700 | 1 |
| 1.500 | Z | 90.000 | 60.135, 16.950, -36.000 | 1 |
| 1.500 | Z | 90.000 | 60.135, 16.950, 36.000 | 1 |
| 1.500 | Z | 90.000 | 70.035, 16.950, -36.000 | 1 |
| 1.500 | Z | 90.000 | 70.035, 16.950, 36.000 | 1 |
| 1.500 | Z | 90.000 | 60.135, 7.050, -36.000 | 1 |
| 1.500 | Z | 90.000 | 60.135, 7.050, 36.000 | 1 |
| 1.500 | Z | 90.000 | 70.035, 7.050, -36.000 | 1 |
| 1.500 | Z | 90.000 | 70.035, 7.050, 36.000 | 1 |

## 结论

- V2 主关节接口复核：`PASS`。
- V2 新增装配孔系校核：`PASS`。
- V2 二级装配孔位校核总体：`PASS`。
- V2 相比 V1 的核心进步是：从只有主孔/轻量化孔，推进到包含明确的舵机安装孔和肩部定位/夹紧孔。
- 仍需说明：由于没有完整官方装配 mating transform 和舵机标准件模型，V2 还不是生产级装配认证；它是作品集阶段的 CAD 特征级改进版。

## 这一步的意义

- V1 证明 AI 可以生成可仿真的轻量化结构。
- V2 证明你开始按机械装配逻辑补孔系、定位和可制造接口，不再停留在外观建模。
- 这一步可以作为实习作品集中“AI 辅助结构迭代 + CAD 特征校核”的关键证据。

## 下一步

建议做 Step 12：将 V2 接回 URDF/PyBullet 做 visual smoke test，并重新做几何/质量/力矩对比，形成 V1 与 V2 的 before-after 表。

## 输出文件

- 圆柱特征 CSV：`<repo>/05_improved_design/upper_arm_v2/mounting_check/upper_arm_v2_mounting_cylinders.csv`
- 结构化校核 JSON：`<repo>/05_improved_design/upper_arm_v2/mounting_check/upper_arm_v2_mounting_check.json`
- 中文报告：`<repo>/05_improved_design/upper_arm_v2/mounting_check/upper_arm_v2_mounting_check_report_zh.md`

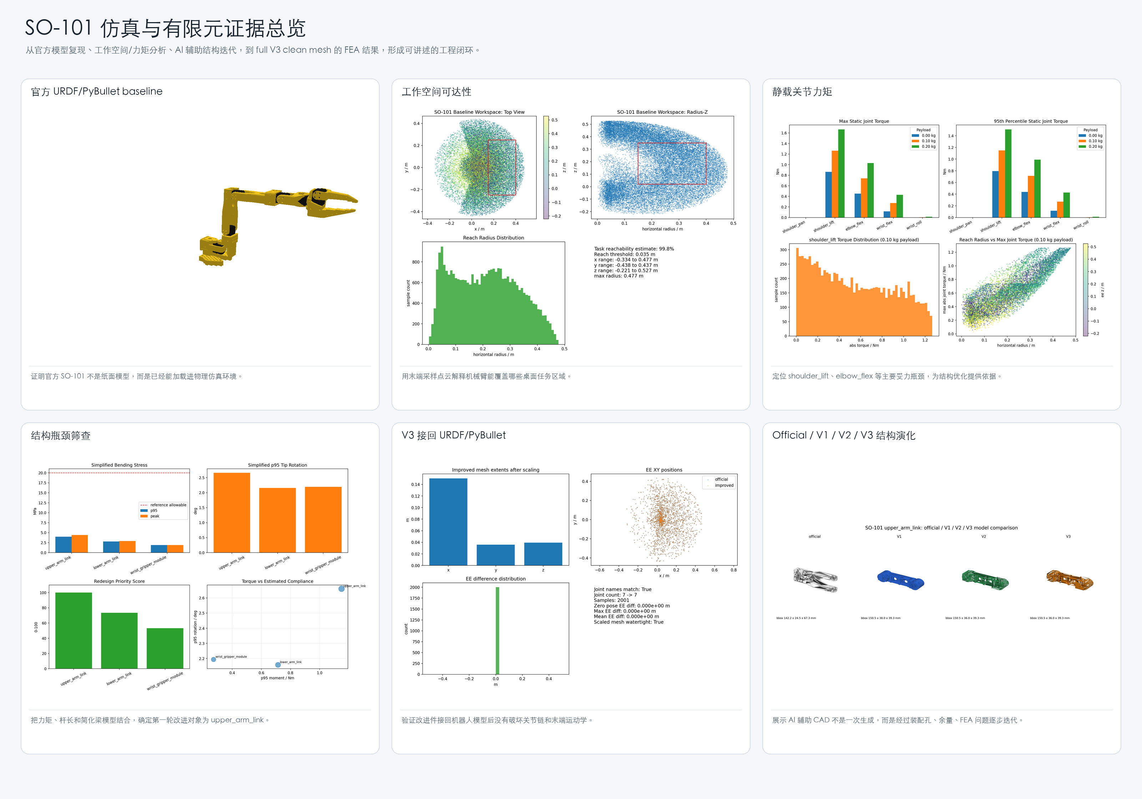
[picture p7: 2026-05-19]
figures/portfolio/fig01_simulation_fea_evidence_overview.png

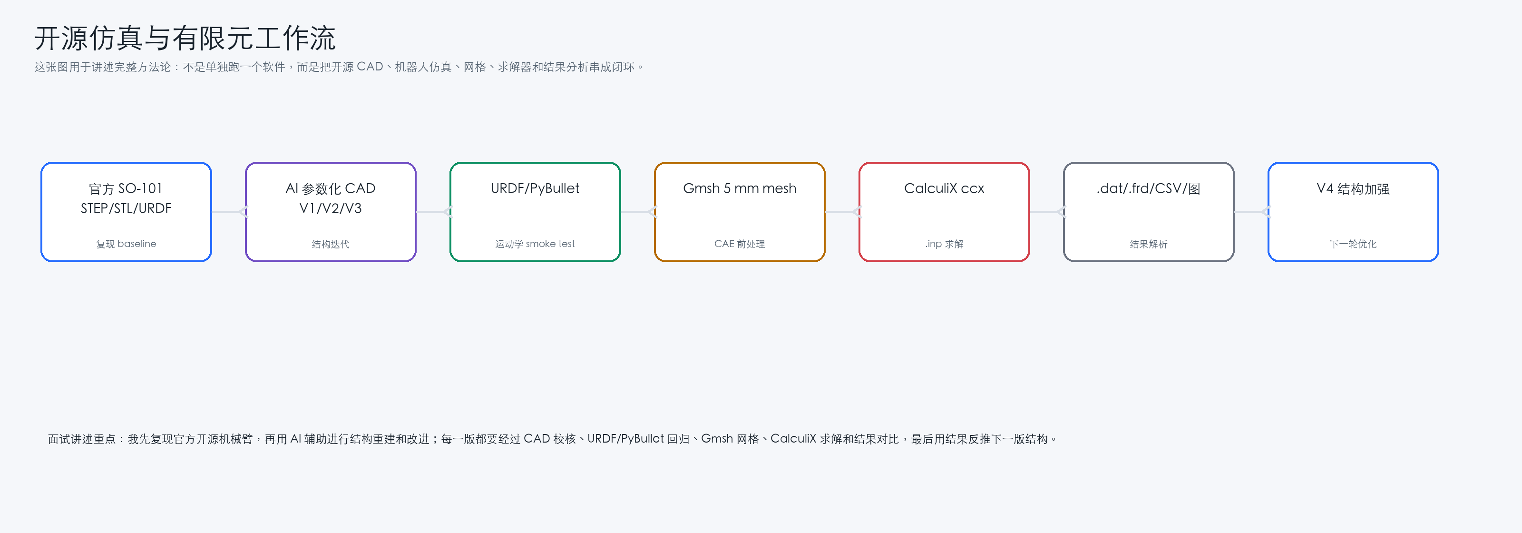
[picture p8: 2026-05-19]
figures/portfolio/fig05_open_source_simulation_cae_workflow.png

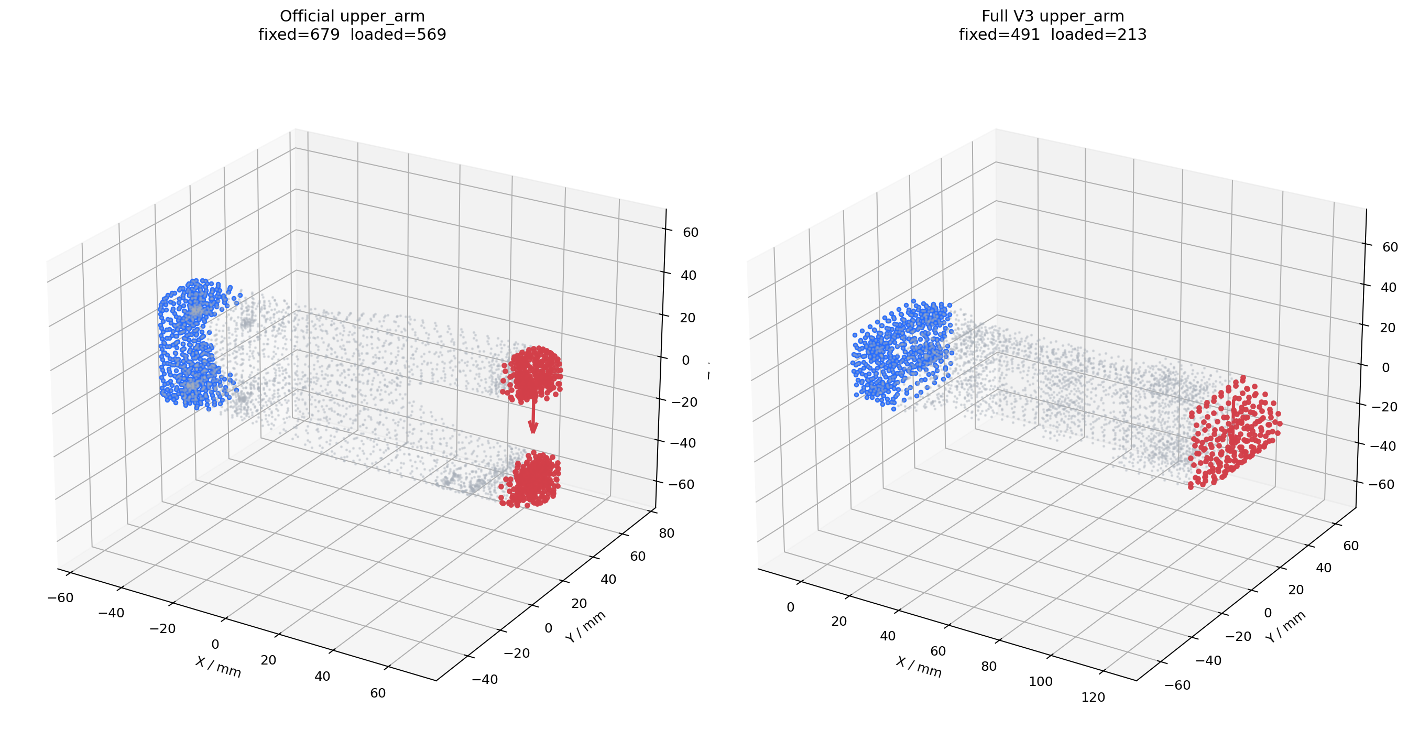
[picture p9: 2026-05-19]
figures/portfolio/fig03a_boundary_node_sets.png

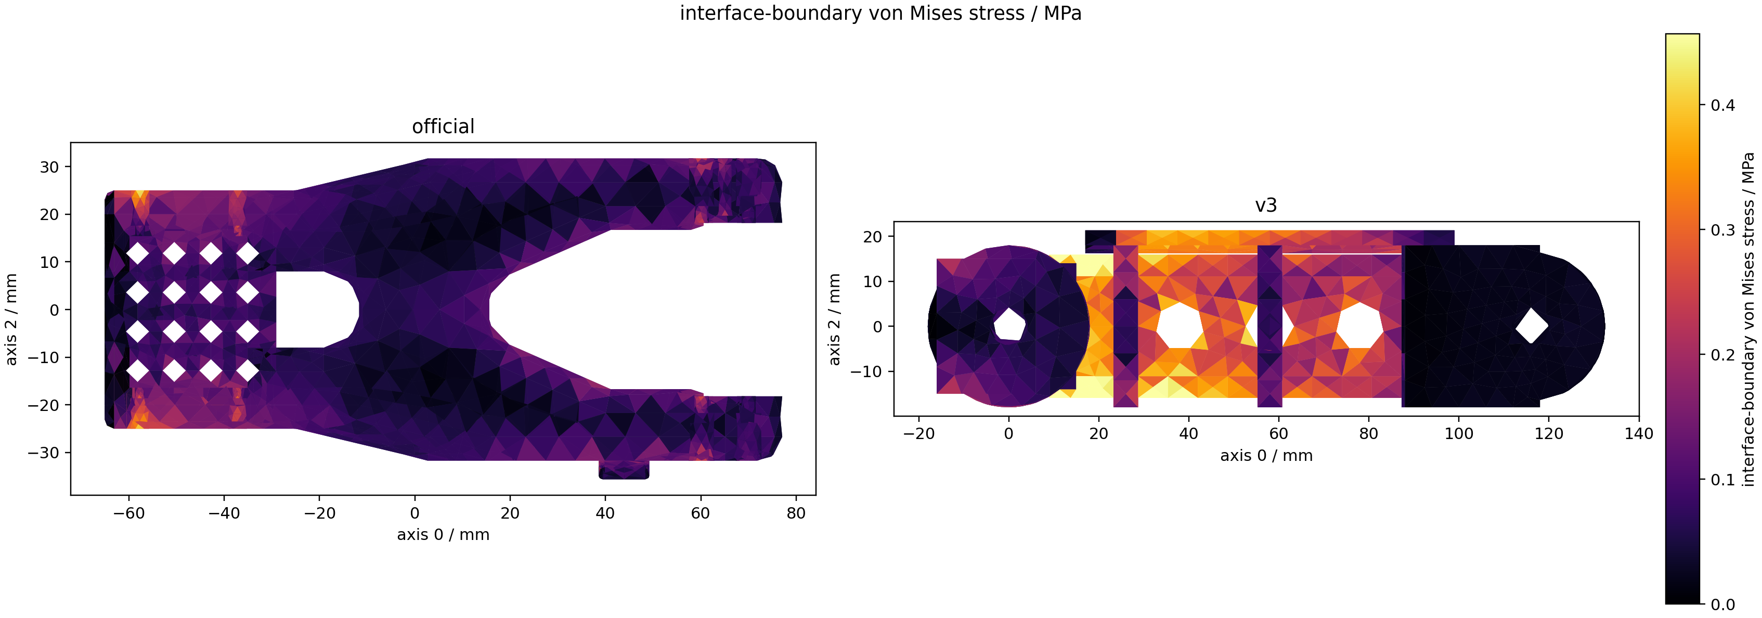
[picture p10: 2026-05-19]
figures/fea/interface_boundary_von_mises.png

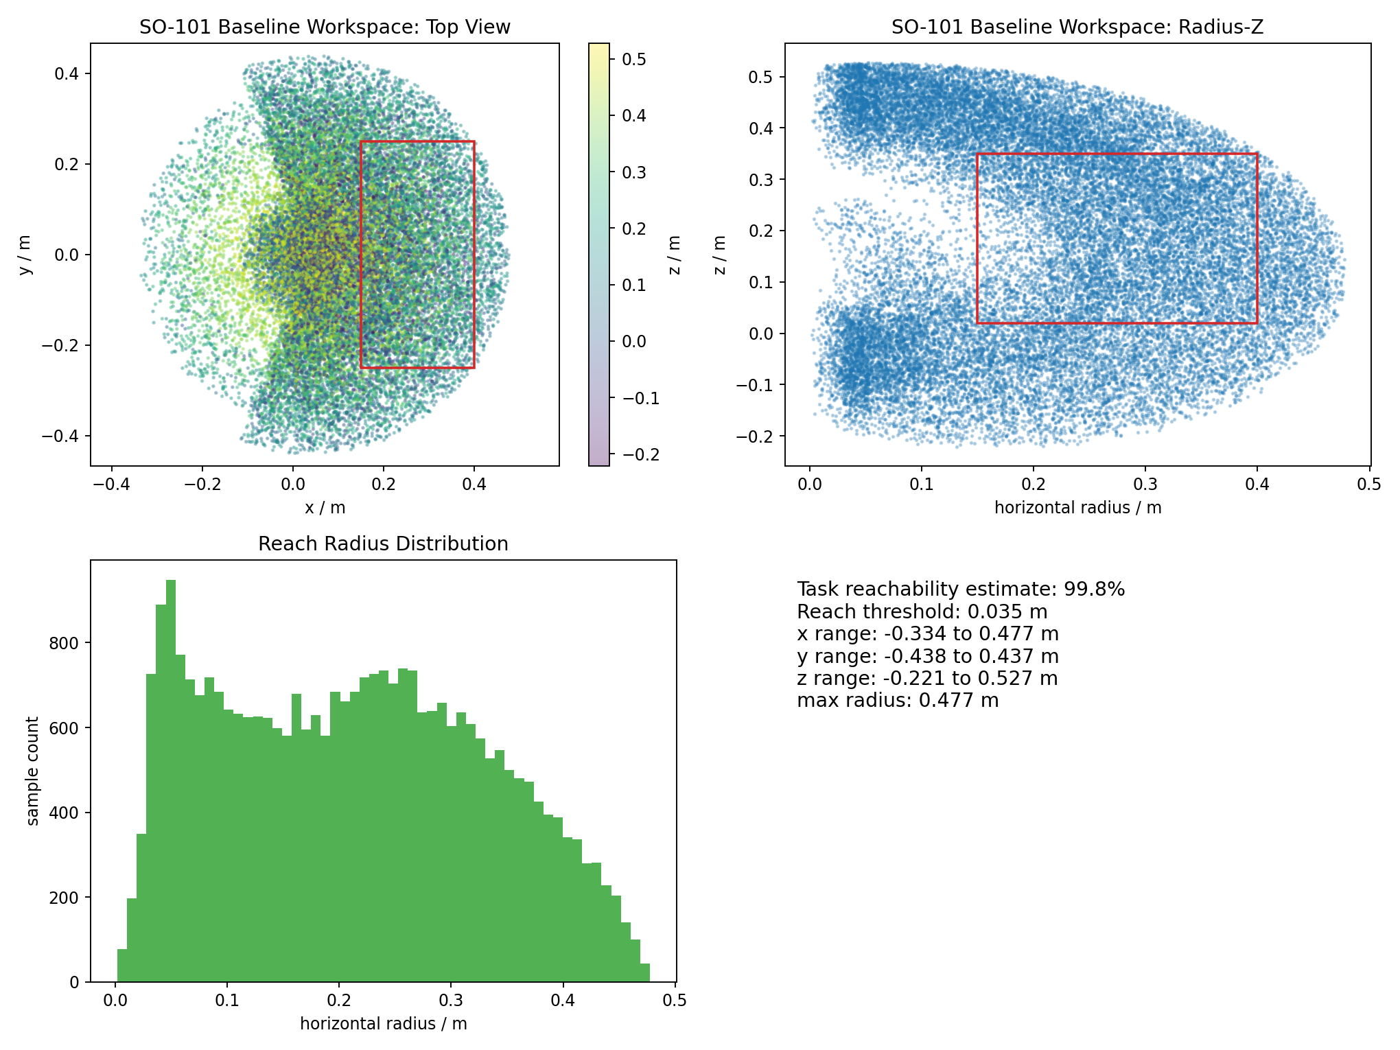
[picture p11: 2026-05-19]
figures/baseline/baseline_workspace_plot.png

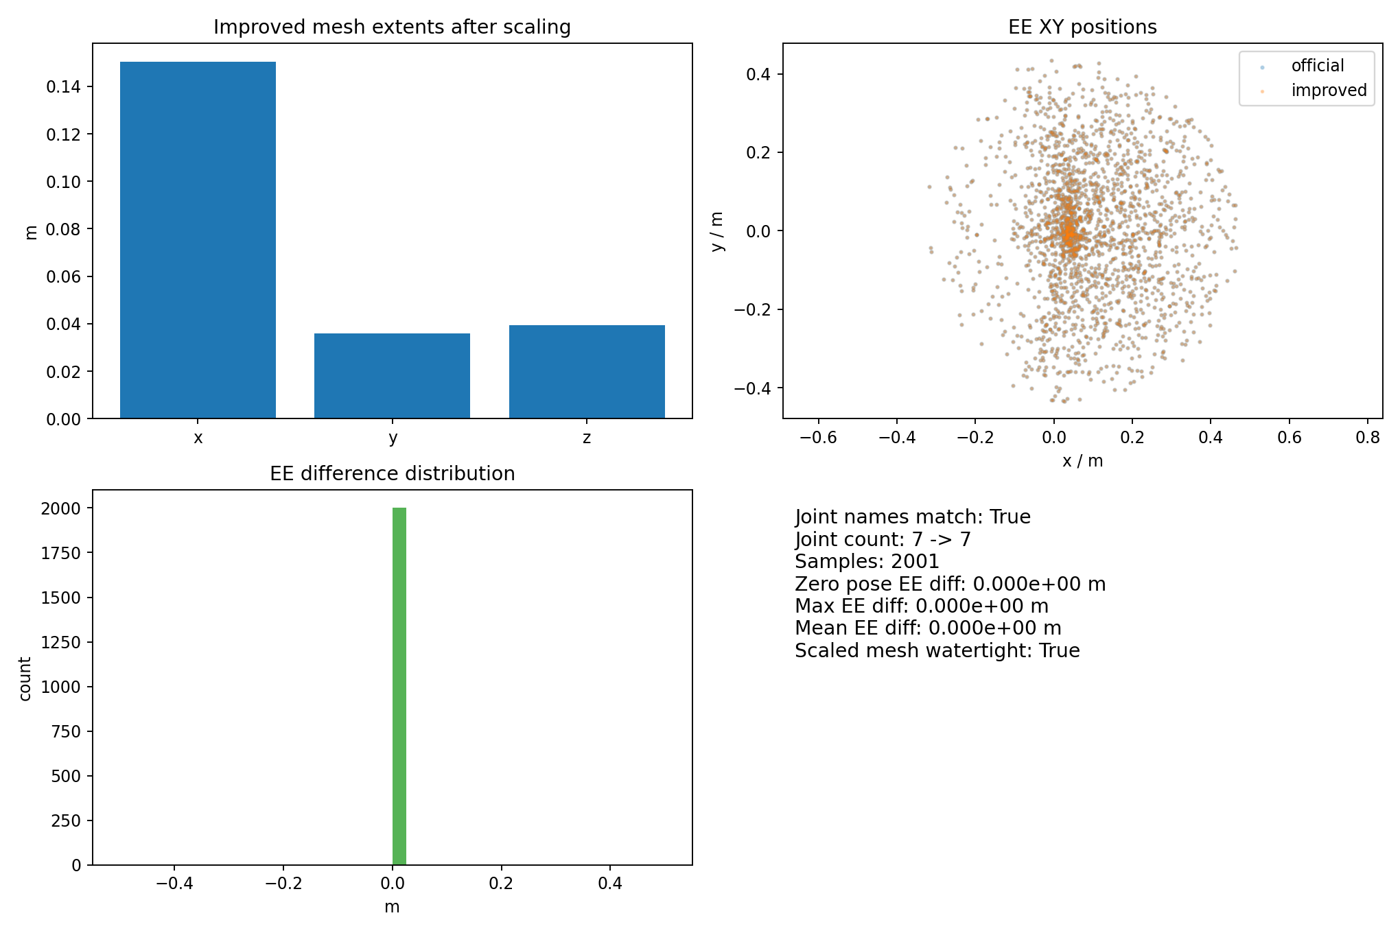
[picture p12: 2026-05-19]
figures/simulation/upper_arm_v3_urdf_smoke_plot.png

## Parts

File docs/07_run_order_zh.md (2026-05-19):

# 推荐复现顺序

> 下面命令需要根据你本机的 SO-101 baseline 资源路径调整脚本中的项目根目录。

## 1. baseline 检查

```bash
python src/baseline_validation/inspect_so101_urdf.py
python src/baseline_validation/random_motion_so101.py
python src/baseline_validation/generate_structure_breakdown.py
```

## 2. 工作空间、力矩和结构瓶颈

```bash
python src/structural_analysis/baseline_workspace_analysis.py
python src/structural_analysis/baseline_static_torque_analysis.py
python src/structural_analysis/baseline_structural_bottleneck_analysis.py
```

## 3. upper arm CAD 生成与校核

```bash
python src/cad/upper_arm_v1/upper_arm_v1_cad.py
python src/cad/upper_arm_v2/upper_arm_v2_cad.py
python src/cad/upper_arm_v3/upper_arm_v3_cad.py
```

随后运行对应版本的 `validate_*`、`mounting_check_*`、`standard_part_assembly_check_*` 和 `urdf_smoke_*` 脚本。

## 4. FEA screening

```bash
python src/fea/run_v3_cae_geometry_cleanup.py
python src/fea/run_full_v3_clean_fea.py
python src/fea/run_calculix_smoke_fea.py
```

## 5. 图表生成

```bash
python src/visualization/generate_upper_arm_model_visuals.py
python src/visualization/generate_simulation_fea_visual_package.py
```

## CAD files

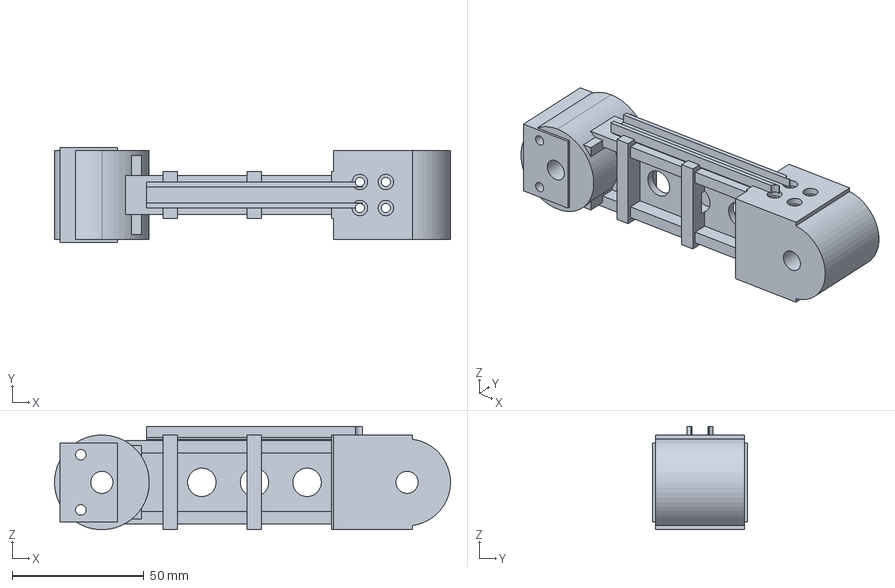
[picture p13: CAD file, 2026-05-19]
models/fea/v3_full_cae_clean_5mm.step
150.5 x 36.0 x 39.3 mm

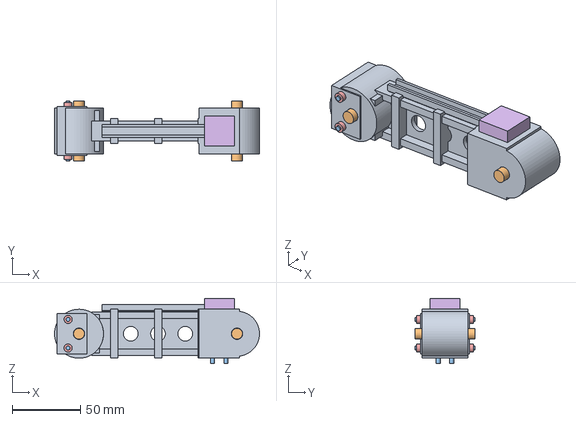
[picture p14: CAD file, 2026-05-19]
projects/text_to_cad_parametric_cad/assemblies/upper_arm_v3_simplified_standard_parts_assembly.step
150.5 x 44.0 x 48.0 mm
so101_upper_arm_v3_ai_rebuild

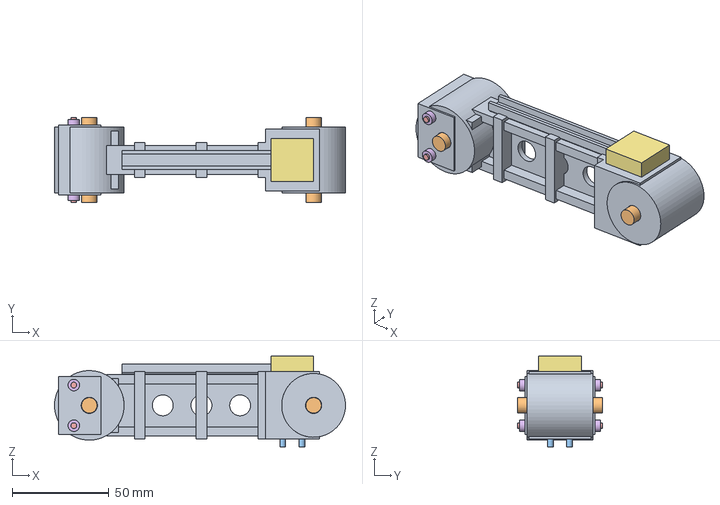
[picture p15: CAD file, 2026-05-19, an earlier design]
projects/text_to_cad_parametric_cad/assemblies/upper_arm_v2_simplified_standard_parts_assembly.step
150.5 x 44.0 x 47.0 mm
so101_upper_arm_v2_ai_rebuild_mounting_features

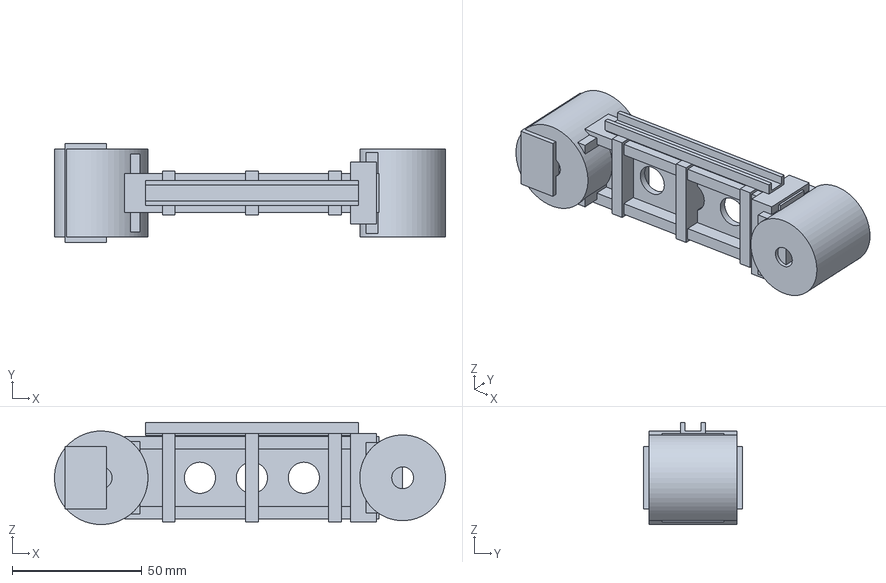
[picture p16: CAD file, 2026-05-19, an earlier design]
projects/text_to_cad_parametric_cad/models/upper_arm_v1_ai_rebuild.step
150.5 x 38.0 x 39.3 mm

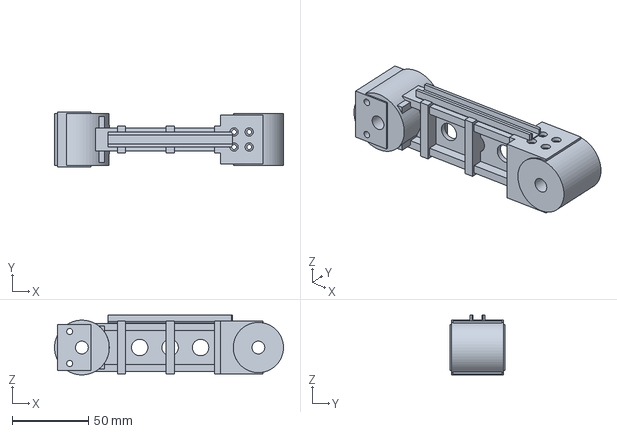
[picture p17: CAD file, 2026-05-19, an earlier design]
projects/text_to_cad_parametric_cad/models/upper_arm_v2_ai_rebuild.step
150.5 x 36.0 x 39.3 mm

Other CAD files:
models/fea/v3_parametric_for_fea_full.step
models/fea/v3_parametric_for_fea.step
projects/text_to_cad_parametric_cad/models/upper_arm_v3_ai_rebuild.step
projects/text_to_cad_parametric_cad/assemblies/upper_arm_v2_simplified_standard_parts_assembly.stl
projects/text_to_cad_parametric_cad/assemblies/upper_arm_v3_simplified_standard_parts_assembly.stl
projects/text_to_cad_parametric_cad/models/upper_arm_v1_ai_rebuild.stl
projects/text_to_cad_parametric_cad/models/upper_arm_v2_ai_rebuild.stl
projects/text_to_cad_parametric_cad/models/upper_arm_v3_ai_rebuild.stl

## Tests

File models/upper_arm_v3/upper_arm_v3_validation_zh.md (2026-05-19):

# upper_arm_link V3 几何验证报告

## 目的

检查 `upper_arm_v3` 是否成功导出为 STEP/STL，并与官方 upper arm、V1、V2 做基础网格几何对比。

V3 的目标不是重新设计整根 upper arm，而是针对 Step 14 暴露的肘部孔系余量问题做局部修复。

## 文件

- 官方 STL：`<repo>/00_source_snapshot/STL_SO101/Individual/Upper_arm_SO101.stl`
- V1 STL：`<repo>/05_improved_design/upper_arm_v1/upper_arm_v1_ai_rebuild.stl`
- V2 STL：`<repo>/05_improved_design/upper_arm_v2/upper_arm_v2_ai_rebuild.stl`
- V3 STL：`<repo>/05_improved_design/upper_arm_v3/upper_arm_v3_ai_rebuild.stl`
- V3 STEP：`<repo>/05_improved_design/upper_arm_v3/upper_arm_v3_ai_rebuild.step`

## 基础几何统计

| 模型 | 顶点数 | 面数 | watertight | 包围盒尺寸 xyz | 体积 | PLA 估算质量 |
|---|---:|---:|---|---:|---:|---:|
| official_upper_arm | 3961 | 8038 | True | 142.15, 24.50, 67.30 mm | 117328.19 mm^3 | 145.49 g |
| upper_arm_v1 | 2192 | 4412 | True | 150.50, 38.00, 39.30 mm | 93885.71 mm^3 | 116.42 g |
| upper_arm_v2 | 5692 | 11436 | True | 150.50, 36.00, 39.30 mm | 98626.10 mm^3 | 122.30 g |
| upper_arm_v3 | 5518 | 11088 | True | 150.50, 36.00, 39.30 mm | 101891.50 mm^3 | 126.35 g |

## 对比结论

- V3 相对官方 STL 体积变化：-15436.69 mm^3，比例 -13.16%。
- V3 相对 V2 体积变化：3265.40 mm^3，比例 3.31%。
- V3 应结合 `assembly_check/upper_arm_v3_standard_part_check_report_zh.md` 判断是否真正修复了 V2 的装配余量风险。

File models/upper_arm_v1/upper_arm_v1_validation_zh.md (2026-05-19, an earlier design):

# upper_arm_link V1 几何验证报告

## 目的

检查 AI 辅助生成的 `upper_arm_v1` 是否成功导出为 STEP/STL，并与官方 upper arm STL 做基础几何对比。

## 文件

- 官方 STL：`<repo>/00_source_snapshot/STL_SO101/Individual/Upper_arm_SO101.stl`
- 改进版 STL：`<repo>/05_improved_design/upper_arm_v1/upper_arm_v1_ai_rebuild.stl`
- 改进版 STEP：`<repo>/05_improved_design/upper_arm_v1/upper_arm_v1_ai_rebuild.step`

## 基础几何统计

| 模型 | 顶点数 | 面数 | watertight | 包围盒尺寸 xyz | 体积 | PLA 估算质量 |
|---|---:|---:|---|---:|---:|---:|
| official_upper_arm | 3961 | 8038 | True | 142.15, 24.50, 67.30 mm | 117328.19 mm^3 | 145.49 g |
| improved_upper_arm_v1 | 2192 | 4412 | True | 150.50, 38.00, 39.30 mm | 93885.71 mm^3 | 116.42 g |

## 对比结论

- 改进版 X 向总包围盒长度约 150.50 mm；设计中保留的 shoulder 到 elbow 轴线间距为 116.0 mm。
- 与官方 STL 相比，改进版体积变化约 -23442.49 mm^3，比例约 -20.0%。
- V1 是参数化概念重建件，重点是建立可编辑 CAD 源文件和结构改进方向，不直接声称已经满足装机打印要求。
- 下一步需要可视化检查外观，并准备把改进 mesh 接回 URDF/PyBullet 做加载测试。

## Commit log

2026-05-19 Initial SO-101 AI CAE portfolio
    [baseline_beam_stress_estimate.csv, official_v1_v2_key_metrics.csv, so101_joint_summary.csv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]
2026-05-19 Add Text-to-CAD workflow documentation
2026-05-19 Clean public docs and add Text-to-CAD module assets
    [upper_arm_v1_ai_rebuild.step, upper_arm_v1_ai_rebuild.stl, upper_arm_v1_mounting_cylinders.csv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]
